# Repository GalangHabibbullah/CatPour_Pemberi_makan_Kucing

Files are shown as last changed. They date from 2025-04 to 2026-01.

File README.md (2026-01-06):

# 🐱 **CatPour** 🐱

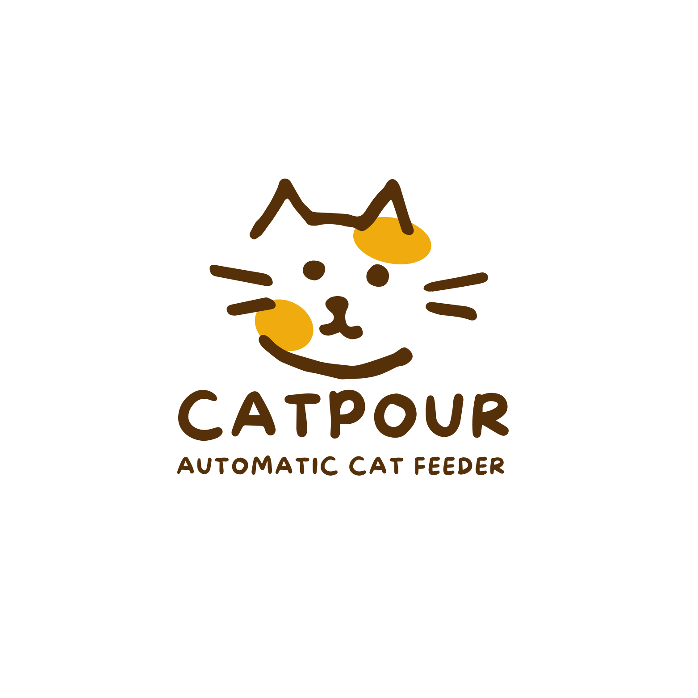
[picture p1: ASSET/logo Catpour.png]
Logo Catpour

---
🐱CatPour🐱 - SOLUSI CERDAS PARA CATLOVERS
Pernah merasa bersalah karena lupa memberi makan kucing karena sedang bepergian jauh? Atau bingung berapa porsi makan kucing yang dibutuhkan? CatPour hadir sebagai solusi cerdas para catlovers

Bayangkan kamu pulang ke rumah setelah berlibur. Kucingmu mengeong karena sedang kelaparan karena makanan yang telah kamu siapkan sudah habis tak bersisa. Tapi tenang kejadian itu tidak akan terulang ketika CatPour hadir.

CatPour hadir untuk menyelesaikan masalah para catlovers ketika sedeang bepergian. Sekarang Catlovers tidak perlu khawatir terhadap kucing piaraanya yang kelaparan, karena Catpour memberikan makanan secara otomatis sesuai jadwal dan dalam porsi yang cukup.

---
## 🎬 Commercial Video
Watch the demo (https://youtube.com/shorts/FYVQH_eTqcQ?si=p7NEjKbdANHq4uou)

---
## BUKU PANDUAN
📘 [Klik di sini untuk melihat buku proyek](./ASSET/buku.pdf)

## Link simulasi Wokwi
-- https://wokwi.com/projects/432622796153693185
-- [https://github.com/GalangHabibbullah/CatPour_Pemberi_makan_Kucing/tree/fe5401d0f07f7c271f16389e5ba98aa213cf10a5/PROGRAM/Wokwi](https://github.com/GalangHabibbullah/CatPour_Pemberi_makan_Kucing/issues/2#issue-3108791988)

---

## Link Video Demo
-- [https://github.com/GalangHabibbullah/CatPour_Pemberi_makan_Kucing/tree/d1d1669227759c1687d57a3f496b5af06effbe53/PROGRAM/Demo](https://github.com/GalangHabibbullah/CatPour_Pemberi_makan_Kucing/issues/1#issue-3108780877)

---

## TINGVERS
-- https://www.thingiverse.com/thing:7054144

---

## LINK PPT PRESENTASI


---

## LINK FIGMA
https://www.figma.com/design/loQbXYYag1uOcxZlFO6y6Z/Untitled?node-id=12-356&p=f&t=XrePOnV4dfjZV4aA-0

---
## 🎯 Objectives

- Mendeteksi jumlah sisa makanan pada bak penampungan makan  
- Memberi makan sesuai dengan porsi si kucing
- Memberi makan secara otomatis sesuai dengan jadwal makan.
- Menyediakan monitoring sisa makanan secara real-time melalui UART ke komputer
---
## 🧠 LATAR BELAKANG
Mempunyai kucing piaraan merupakan kesenangan sebagian orang, sering kali juga menjadi tantangan dalam hal pemberian makan, terutama bagi orang-orang sibuk atau yang sering  bepergian. Salah satu penyebab ketidakaturan ini bisa berdampak pada kesehatan kucing

**CatPour** memberikan solusi dengan cara pemberian makan otomatis sesuai porsi makan kucing  yang dibutuhkan.

---

Logo Catpour
## 🦾 Support BY :
>- Dosen Pengampu : Akhmad Hendriawan ST., MT. (NIP.197501272002121003)<br>
>- Mata kuliah : Workshop Mikrokontroller<br>
>- Program Studi : D3 Teknik Elektronika<br>
>- Politeknik Elektronika Negeri Surabaya<br>
---
## 😎 Team Member
| NRP | Nama | Jobdesk | Akun |
| :---: |:---: | :---: | :---:|
| 2123500004 | Rachmat Dhani G | 3D Design | [Dhani](https://github.com/rachmatdhani)
| 2123500005 | M. Ghibran K | Hardware | [Ghibran](https://github.com/Smolyyymokka)
| 2123500020 | Adhitya Ramadhani | UI / UX Design | [Firman](https://github.com/adhitya161004)
| 2123500025 | Adhi Pramana R | Programmer | [Rama](https://github.com/Adhi-Rama)
| 2123500030 | Galang Habibbullah| Project Manager | [Galang](https://github.com/GalangHabibbullah)
---
## 🔗 KOMPONEN 🔗 

Proyek ini mengembangkan sistem pemberian makan kucing otomatis berbasis IoT menggunakan komponen utama seperti **Arduino Uno**, **RTC (Real-Time Clock)**, **Loadcell**, dan **sensor HC-SR04**. 
| Komponen | Fungsi |
|---|---|
| **Arduino Uno** | Berfungsi sebagai mikrokontroler utama yang mengontrol sistem, komunikasi sensor, dan pengaturan pemberian makan otomatis. |
| **RTC** | Menjaga sinkronisasi waktu untuk pemberian makan sesuai jadwal yang telah diatur. |
| **Loadcell** | Mengukur berat makanan di wadah makan untuk memastikan porsi makanan yang tepat. |
| **Sensor HC-SR04** | Untuk memonitoring jumlah kesediaan ppakan dipenampungan pakan. |
---
## Desain 3D PCB
Desain 3D VIEW KICAD

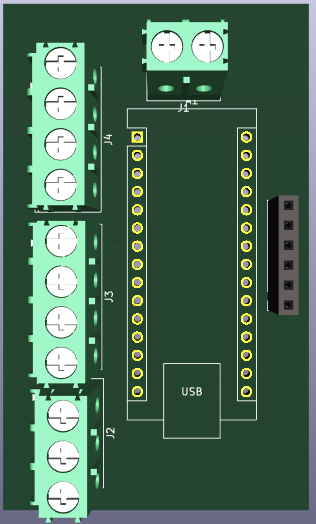
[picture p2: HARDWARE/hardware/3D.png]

---

## Desain Schematic PCB
Desain Schematic 

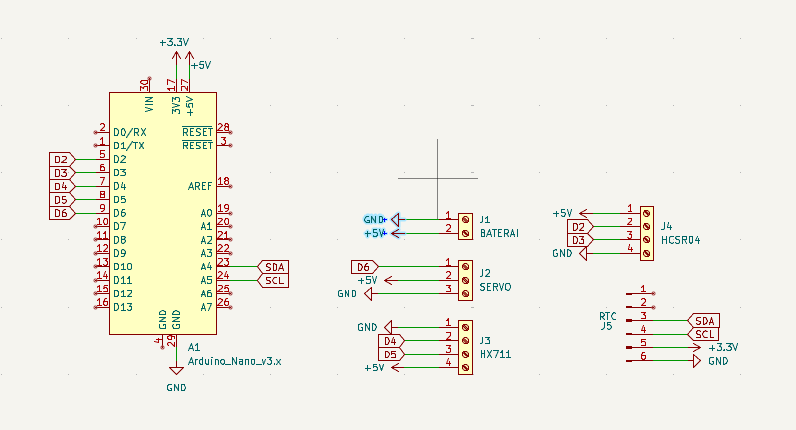
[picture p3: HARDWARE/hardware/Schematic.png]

---
## Desain Layout
Desain Layout PCB 

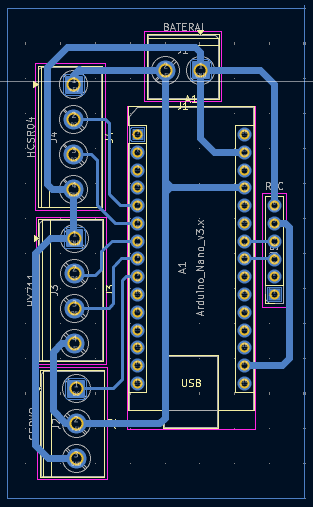
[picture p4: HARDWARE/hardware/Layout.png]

---
## Desain  PCB JADI
Hasil Cetak PCB

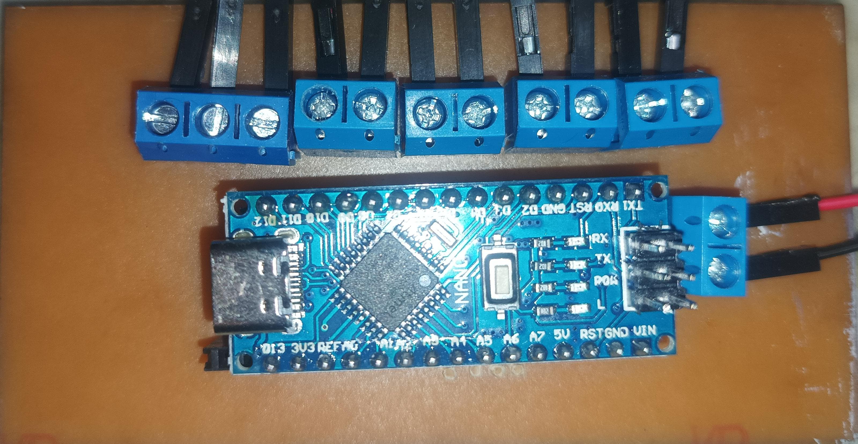
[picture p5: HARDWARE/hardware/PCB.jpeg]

---
## Desain 3D Alat
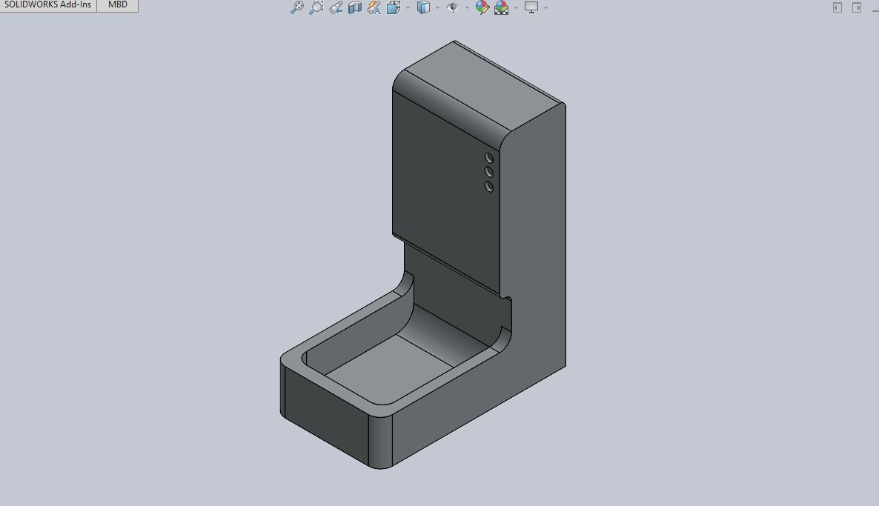
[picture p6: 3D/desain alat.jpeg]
Desain Alat

---
## Desain Jadi
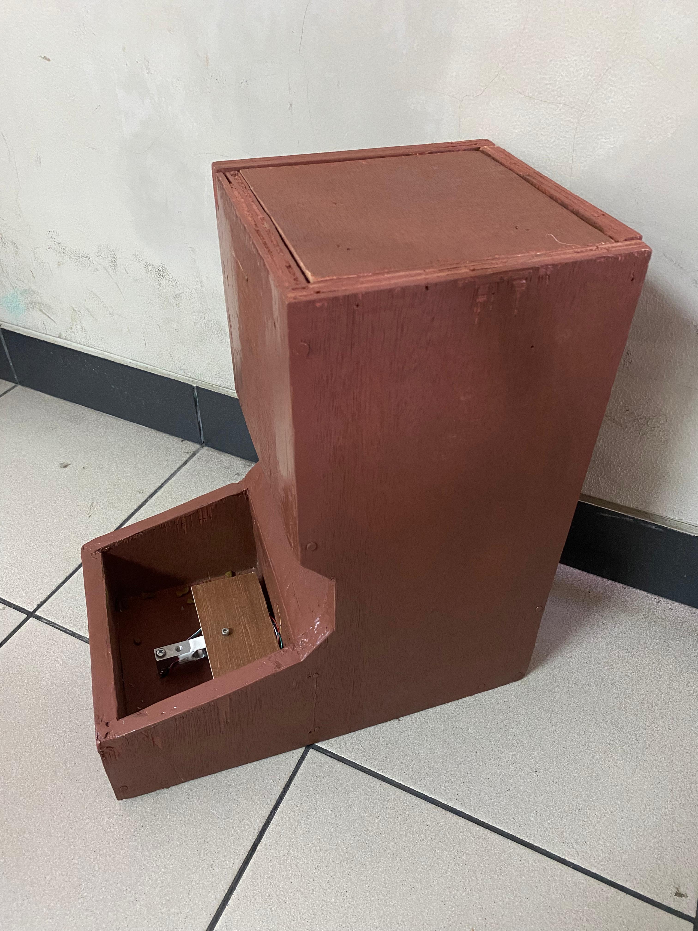
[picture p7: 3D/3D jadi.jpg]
Desain 3D Jadi

---
## 📊Diagram Blok
Diagram Blok Sistem.

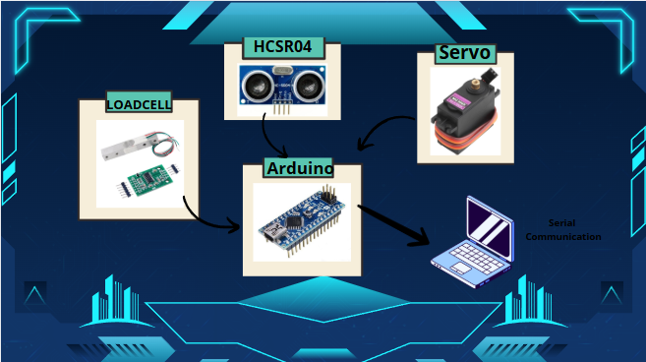
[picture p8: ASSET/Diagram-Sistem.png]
Diagram Komponen

---

## Software Tools

- [Arduino IDE](https://www.arduino.cc/en/software)
- [KiCad](https://kicad.org/)
- [Figma](https://www.figma.com/)
- [Visual Studio Code](https://code.visualstudio.com/)
---
## PRINSIP KERJA 
## Pembacaan penampungan makan
- Sensor HCSR 04 mengirim nilai jarak yang dikonversi menjadi nilai %
100 % = Penampungan Makan Full ; 0 % = Penampungan Makan Kosong
- Sensor Loadcell membaca berat pakan kucing yang keluar, apabila mencapai 20 gram maka servo akan menutup
## Pemrosesan oleh Arduino 
- Arduino  Membaca data  sensor secara berkala, Keputusan diambil untuk membuka servo atau menutup servo
## Tampilan Gui 
- GUI akan menampilkan data berat, sisa makan dan juga posisi servo

--- 
## Pengembangan Kedepannya
- Penambahan Kamera untuk pemantauan jarak jauh
- Penambahan Pemberi minum secara otomatis

---
## 📫 Contact Information

untuk segala informasi, kolaborasi, dan juga pemesanan alat bisa kirim email dibawah ini

**📧 Email:** galanghabibbullah3@gmail.com)

Hanya aktif saat jam kerja, berikan subjek pada email agar  dibalas lebih cepat

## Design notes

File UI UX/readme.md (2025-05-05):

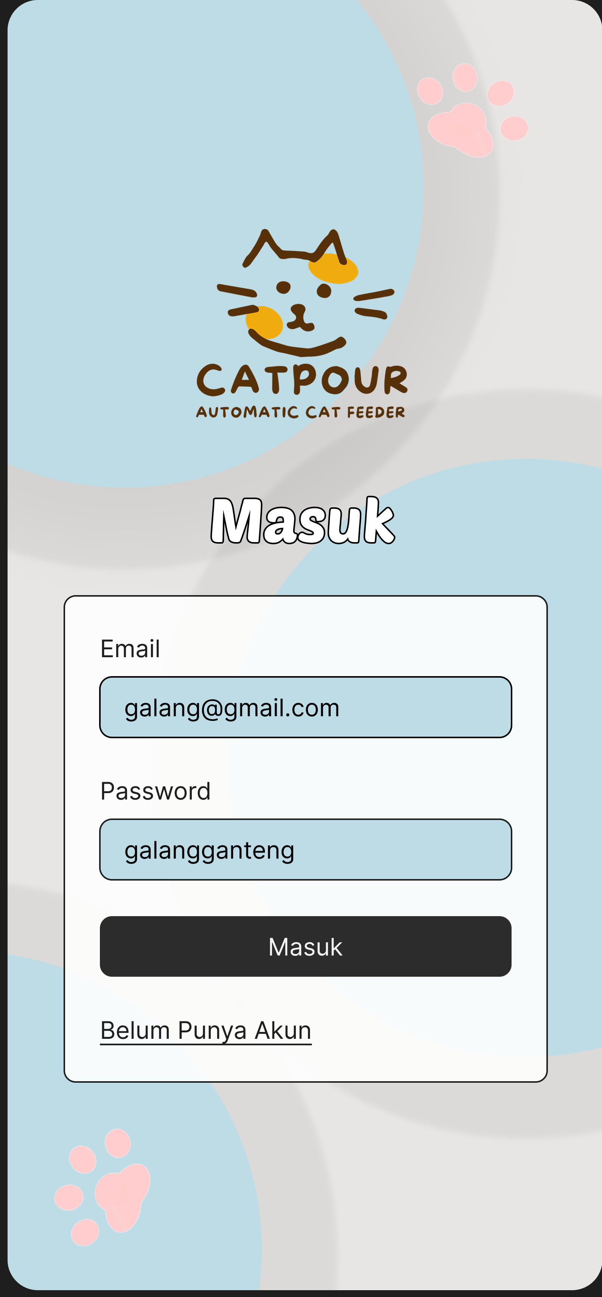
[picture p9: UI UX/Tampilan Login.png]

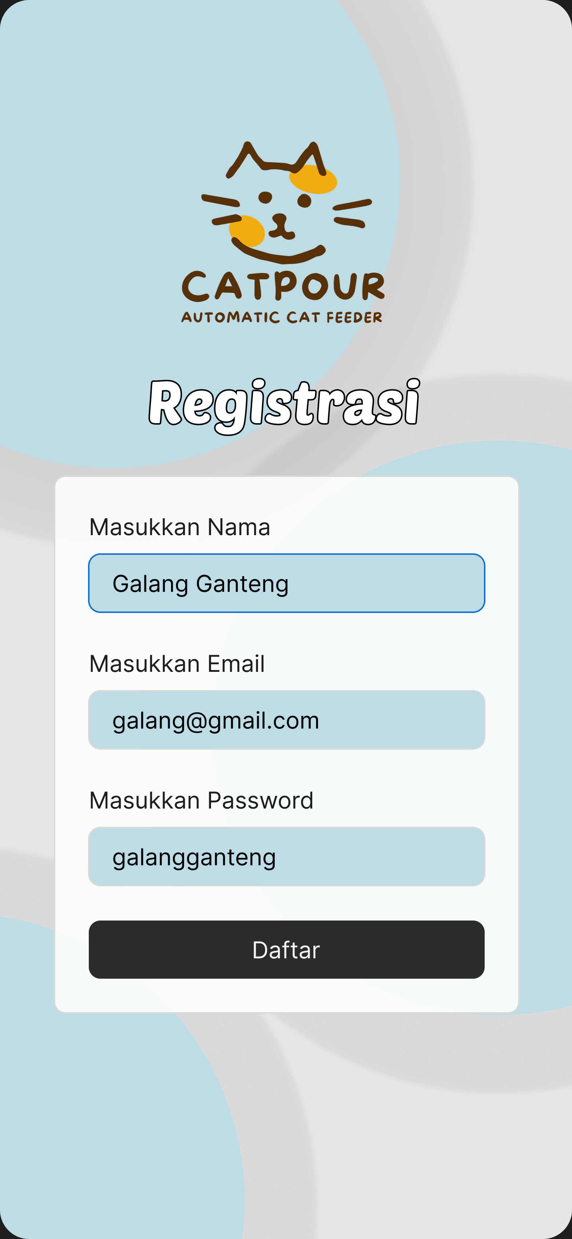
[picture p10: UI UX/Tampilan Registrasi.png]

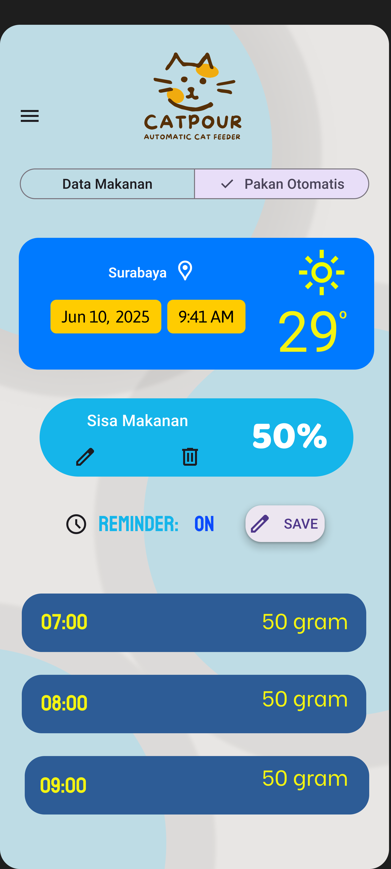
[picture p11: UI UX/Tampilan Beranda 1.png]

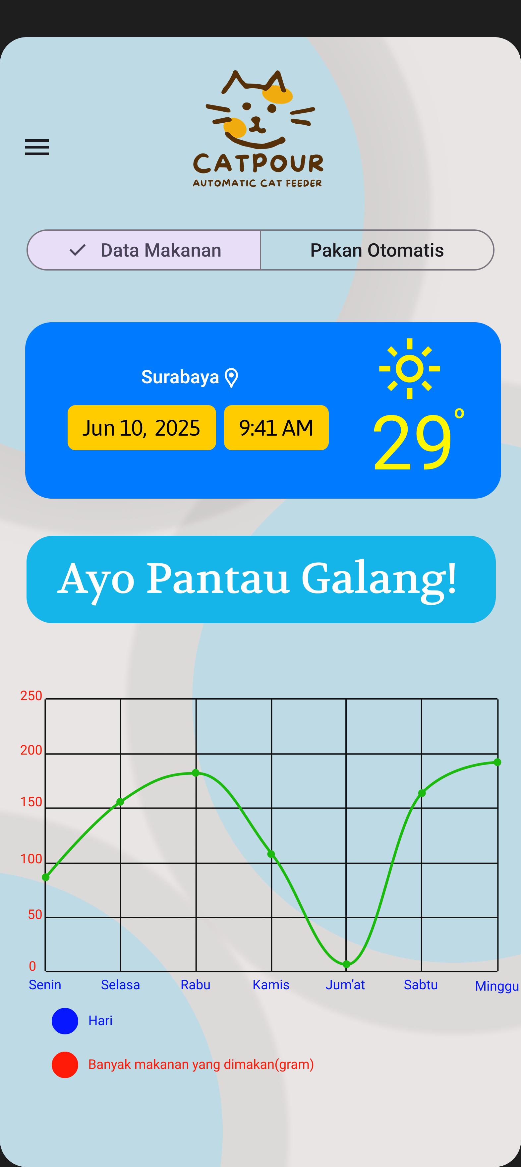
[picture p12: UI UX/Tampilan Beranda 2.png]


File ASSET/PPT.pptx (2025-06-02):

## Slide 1

catpour

(alat pemberi makan kucing otomatis)

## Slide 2

Anggota kelompok

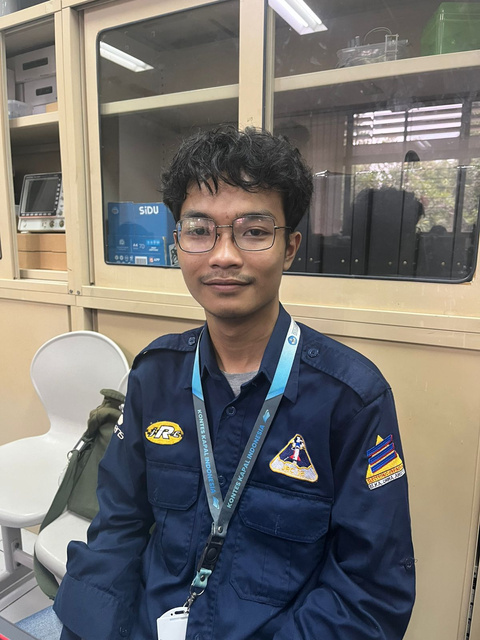
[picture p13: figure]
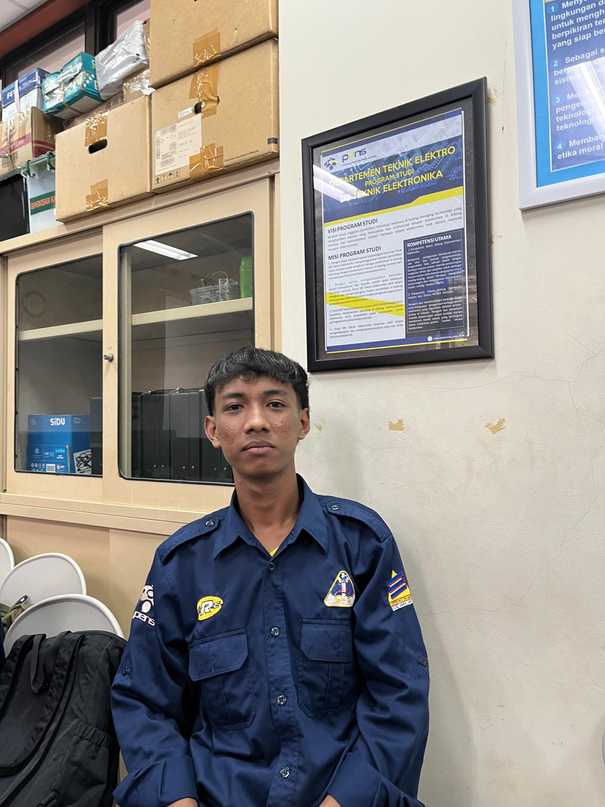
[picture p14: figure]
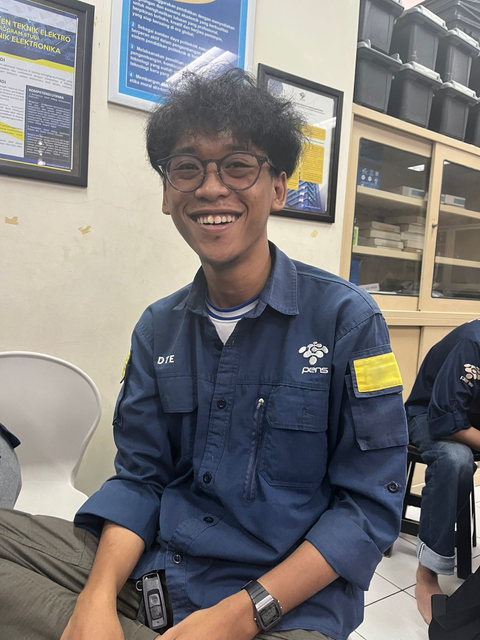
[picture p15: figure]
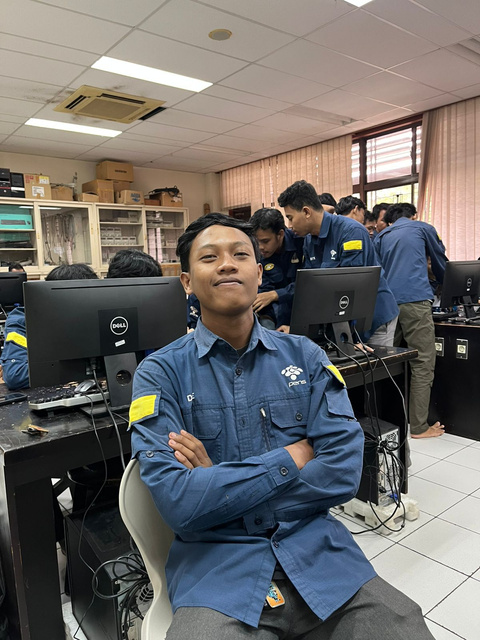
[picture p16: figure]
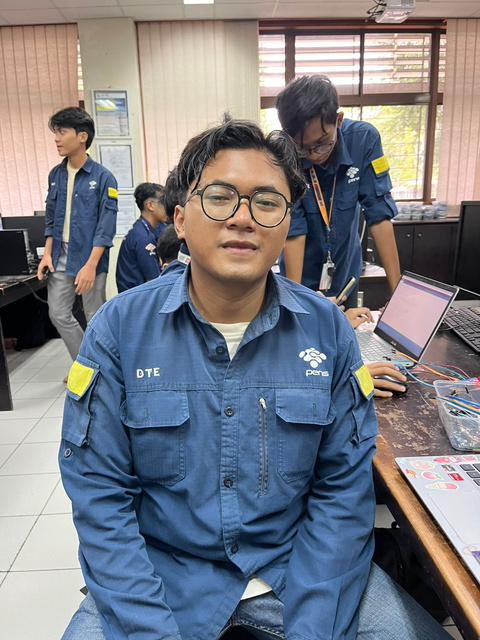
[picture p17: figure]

Rachmat Dhani G
2123500004
3D Design

Muhammad Ghibran
2123500005
Hardware

Adhitya R.N.F
2123500020
UI/UX Design

Adhi Pramana
2123500025
Programer

Galang Habibbullah
2123500030
Project Manager

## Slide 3

latar belakang
catpour

Banyak pemilik kucing mengalami kesulitan dalam memberi makanan kucing secara teratur karena kesibukan atau berpergian keluar rumah. Pemberian pakan yang tidak teratur ini bisa berdampak pada kesehatan kucing. Untuk mengatasi masalah tersebut, Maka kelompok kami merancang alat yang bernama CatPour yaitu alat pemberi makan kucing secara otomatis yang dapat menjadwalkan dan mengatur porsi makanan. Dengan bantuan CatPour pemilik dapat memberi makan kucing secara teratur meskipun pemilik kucing memiliki kesibukan dan berpergian diluar rumah. Dengan Catpour pemilik tidak perlu khawatir kucing peliharaanya merasa kelaparan.

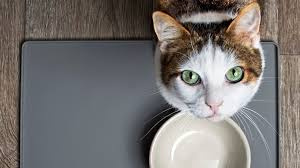
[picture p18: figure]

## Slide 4

rumusan masalah

Bagaimana merancang alat pemberi makan kucing otomatis yang dapat bekerja secara terjadwal?

2

Bagaimana cara mengatur porsi makanan kucing secara otomatis dan akurat?

3

Bagaimana memastikan alat bekerja secara stabil dan aman bagi hewan peliharaan?

1

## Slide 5

Tujuan

Tujuan dari pembuatan alat CatPour ini adalah mengatasi permasalahan yang terjadi pada pemelihara kucing yang memiliki kesibukan dan sering berpergian. Alat ini menja solusi cerdas, praktis, dan penuh kasih bagi para pemilik kucing yang ingin memastikan hewan peliharaannya tetap terjaga kesehatannya, meskipun mereka sedang sibuk atau bepergian. CatPour hadir tidak hanya sebagai alat pemberi makan otomatis, tetapi sebagai "asisten pribadi kucing" yang mampu menyesuaikan waktu, porsi, dan jenis makanan dengan cerdas.

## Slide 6

manfAat catpour

1

Pemberian makan secara terjadwal :
Alat ini membantu pemilik dapat mengatur jadwal pemberian makan tepat waktu meskipun sedang sibuk atau berpergian.

2

Meningkatkan efisiensi waktu :
Pemilik tidak perlu khawatir terhadap pemberian makanan pada kucingnya sehingga pemilik dapat melakukan kegiatan lainnya.

3

Mengatur porsi dengan akurat :
Alat ini Mencegah kucing peliharaan makan secara berlebihan atau kurang, yang bisa berdampak pada kesehatan kucing.

4

Membantu Membentuk Rutinitas Makan
Pemberian pakan yang terjadwal dapat membentuk rutinitas kucing sehingga pemilik dapat mengetahui jadwal makan kucingnya.

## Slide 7

HardWare

Berikut adalah diagram sistem dari CatPour :

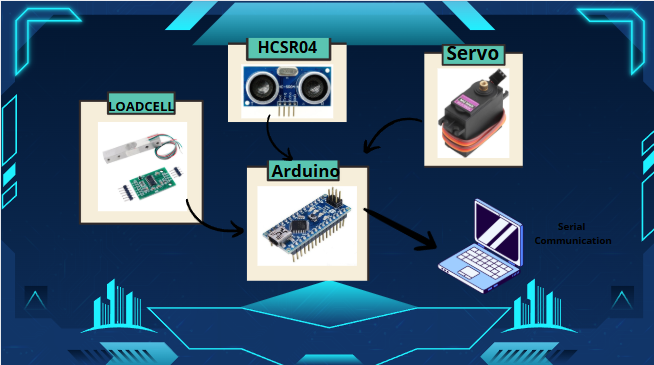
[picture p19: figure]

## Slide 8

Design Hardware

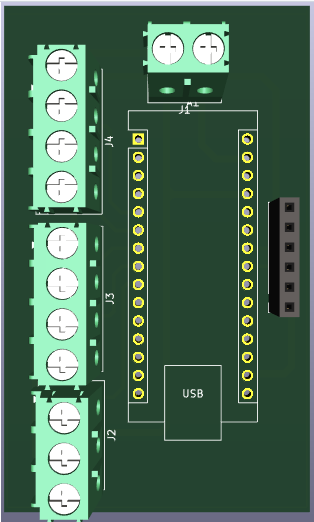
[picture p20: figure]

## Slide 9

Design ALat

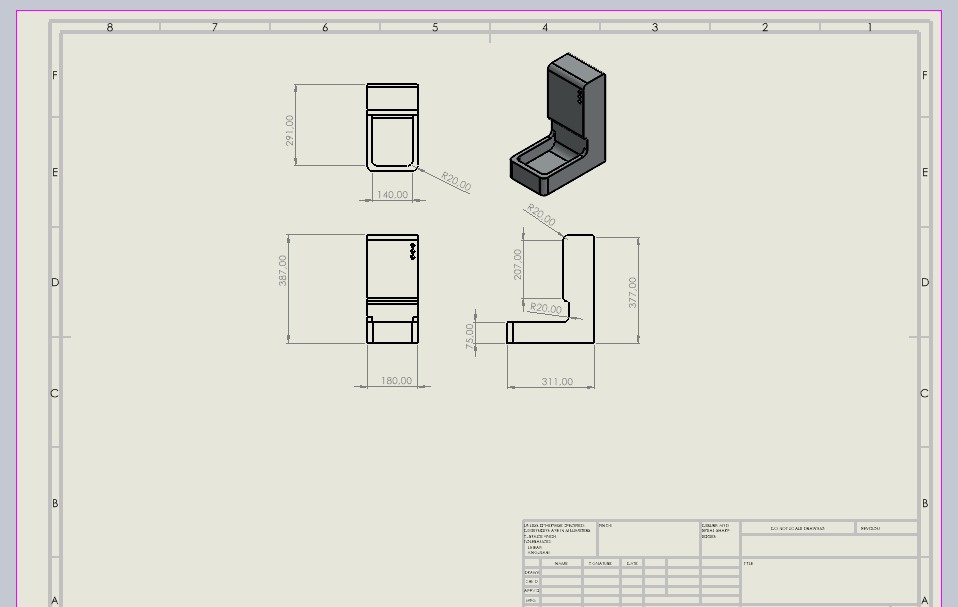
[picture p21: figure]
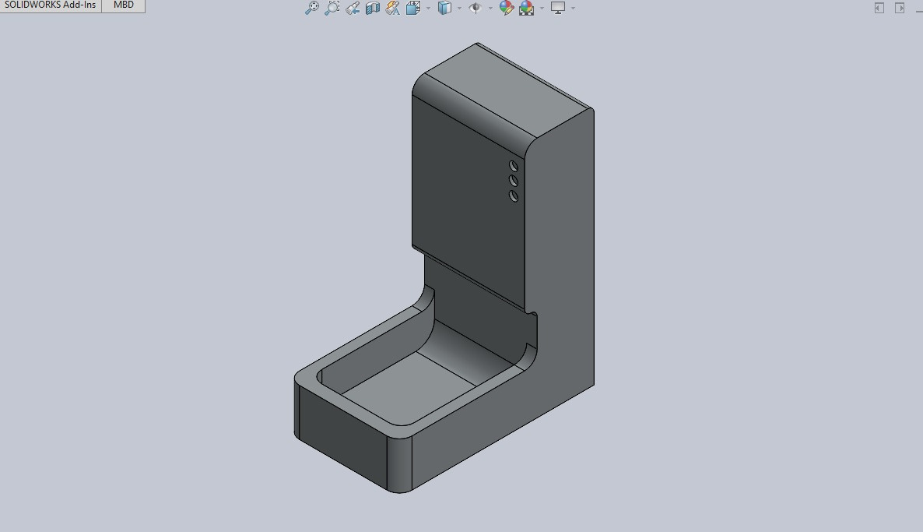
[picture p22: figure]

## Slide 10

UI/UX

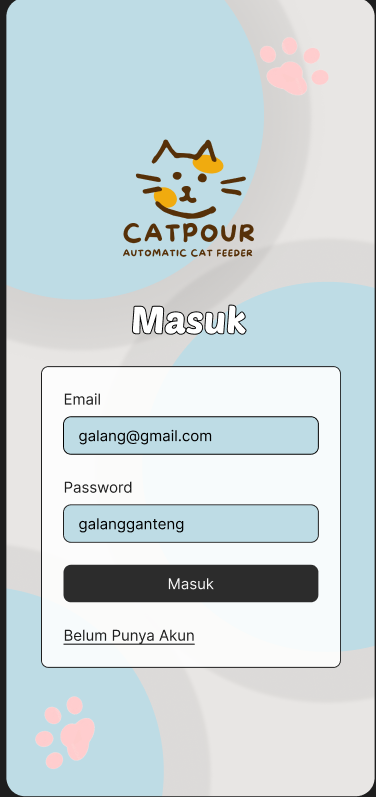
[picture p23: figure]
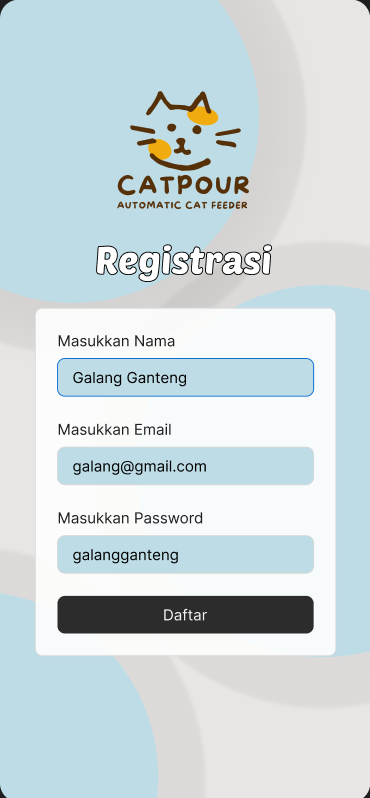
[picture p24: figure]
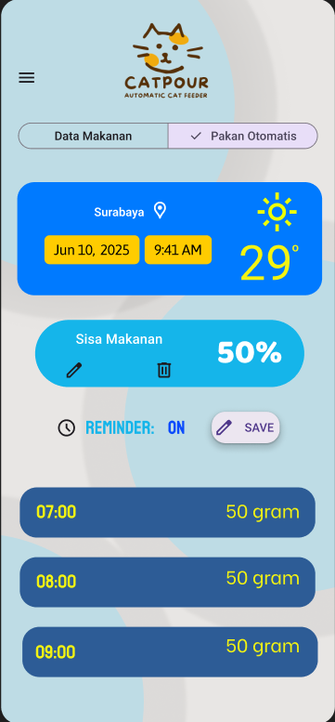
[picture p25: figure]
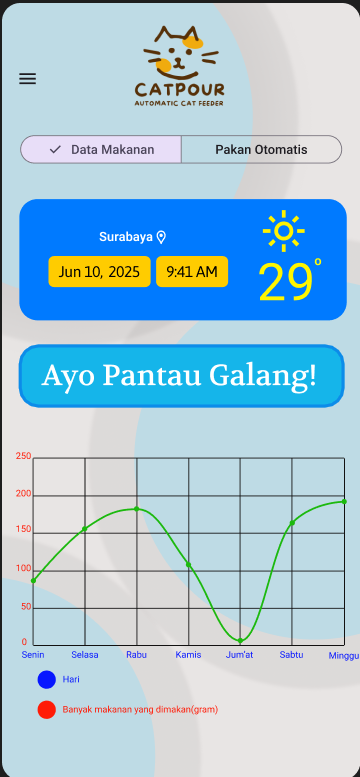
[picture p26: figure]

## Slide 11

Terima
kasih

Semoga Bermanfaat

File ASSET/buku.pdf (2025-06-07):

ww

## www

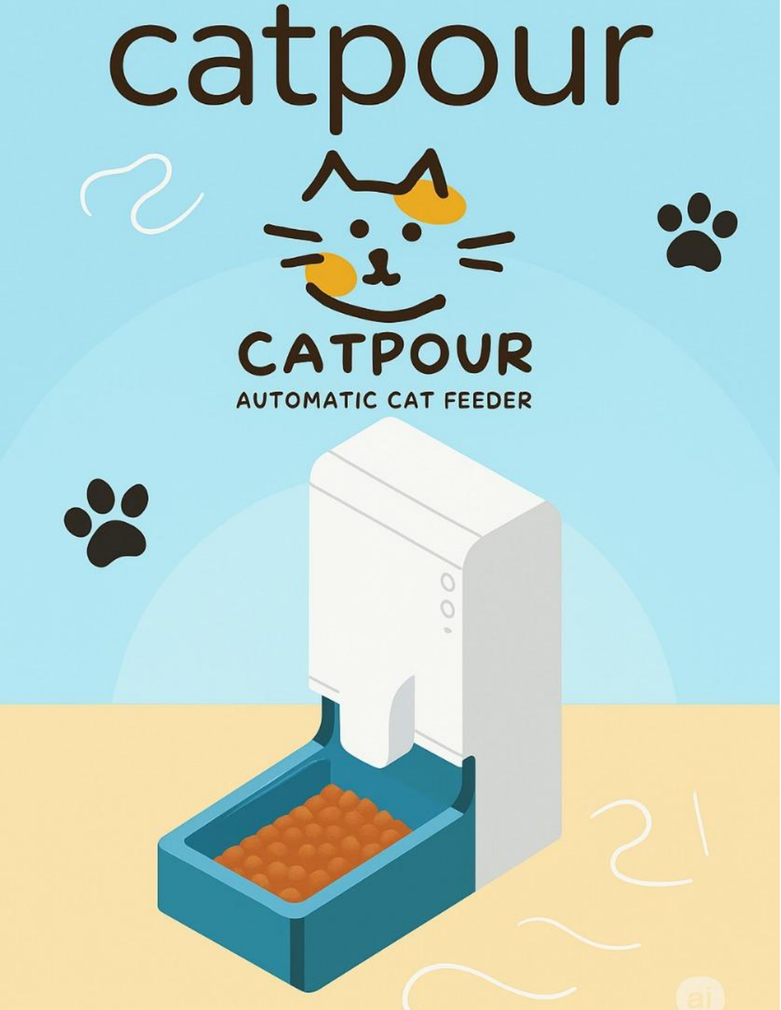
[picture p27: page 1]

## wwww

## wwww

## wwww

## wwwww

## wwwww

## wwwww

## wwww

## DAFTAR ISI

### 5.4 Waktu Respon Sistem | 80

BAB VI DAMPAK MANFAAT DAN PENGEMBANGAN | 82

### 6.1 Manfaat Bagi Pengguna dan Hewan Peliharaan | 82

### 6.2 Dampak Sosial dan Edukasi | 84

### 6.3 Potensi Pengembangan Teknologi | 86

### 6.4 Dampak Terhadap Inovasi Lokal dan Ekonomi Kreatif | 90

### 6.5 Arah Pengembangan Jangka Panjang | 93

BAB VII PENUTUP | 97

### 7.1 Kesimpulan | 97

### 7.2 Keterbatasan | 100

### 7.3 Saran | 102

## BAB I PENDAHULUAN

## 1.1 Latar Belakang

Di era globalisasi yang ditandai oleh percepatan teknologi informasi dan otomasi, kehidupan manusia telah mengalami transformasi signifikan di berbagai bidang, termasuk dalam aspek domestik seperti perawatan hewan peliharaan. Hewan peliharaan tidak lagi hanya dipandang sebagai penjaga atau penghibur semata, tetapi telah menjadi bagian integral dari keluarga dan kehidupan sosial masyarakat modern. Fenomena ini dapat dilihat dari meningkatnya minat terhadap adopsi hewan peliharaan, terutama kucing, yang telah menjadi salah satu hewan peliharaan paling populer di dunia.

Menurut data dari berbagai asosiasi pecinta hewan internasional dan lokal, populasi kucing peliharaan terus meningkat setiap tahunnya. Hal ini tidak terlepas dari karakteristik kucing yang cenderung mandiri, tidak membutuhkan ruang yang luas, dan mampu beradaptasi dengan gaya hidup urban yang padat. Dalam konteks ini, muncul berbagai tantangan baru dalam hal perawatan dan pemeliharaan kucing, khususnya terkait pemenuhan kebutuhan dasar seperti pemberian pakan.

Pemberian pakan merupakan aspek penting dalam menjaga kesehatan dan kesejahteraan kucing. Ketidakteraturan dalam jadwal dan jumlah pakan dapat menyebabkan obesitas, malnutrisi, hingga gangguan perilaku. Namun, kesibukan pemilik sering kali membuat pemberian pakan secara konsisten menjadi sulit. Situasi seperti dinas luar kota, liburan, atau kondisi darurat menyebabkan sistem pemberian pakan manual menjadi tidak memadai.

Solusi yang diperlukan adalah alat pemberi pakan otomatis yang bekerja secara mandiri, teratur, terukur, dan dapat dipantau dari jarak jauh. Dalam konteks ini, teknologi otomatisasi dan Internet of Things (IoT) menjadi jawaban. Otomatisasi kini menjadi bagian penting dari revolusi industri keempat. Perangkat pintar (smart devices) memungkinkan fungsi kompleks dijalankan secara otomatis. Dalam bidang perawatan hewan, berbagai produk seperti penyaring kotoran otomatis dan mainan interaktif telah dikembangkan, namun umumnya masih mahal dan kurang fleksibel.

Berawal dari kondisi ini, dikembangkanlah "Cat Pour", sebuah alat pemberi pakan kucing otomatis yang berbasis mikrokontroler Arduino Nano. Arduino Nano dipilih karena ukurannya kecil, hemat energi, dan kompatibel dengan berbagai sensor dan aktuator. Sistem ini memanfaatkan sensor ultrasonik HC-SR04 untuk mendeteksi posisi wadah, load cell HX711 untuk mengukur berat pakan, dan servo motor sebagai pengatur saluran pakan. Keseluruhan komponen ini bekerja terpadu, memastikan pemberian pakan terjadwal dan sesuai takaran. Desain mekanik alat ini menggunakan kayu triplek sebagai rangka utama, dipilih karena kuat, mudah dibentuk, ramah lingkungan, dan estetis. "Cat Pour" tidak hanya efisien secara fungsi, tetapi juga menyatu secara visual dengan interior rumah.

Sistem ini memiliki potensi dikembangkan menjadi perangkat IoT dengan penambahan modul ESP8266 atau ESP32, memungkinkan kendali dan pemantauan melalui internet. Pengguna dapat menerima notifikasi, mengubah jadwal, atau memantau status pakan dari jarak jauh Selain fungsi praktis, "Cat Pour" juga merupakan sarana edukatif. Dengan desain open-source, alat ini dapat menjadi media pembelajaran untuk mikrokontroler, sensor, aktuator, dan IoT bagi pelajar, mahasiswa, serta komunitas teknologi. Akses terbuka terhadap desain dan kode sumbernya memungkinkan inovasi lebih lanjut.

Dari sisi komersial, "Cat Pour" memiliki potensi sebagai produk lokal yang bersaing dengan produk luar. Biaya produksi yang lebih rendah dan kemudahan pengembangan menjadikan alat ini solusi alternatif yang terjangkau. Dengan prinsip mekatronika, otomasi, dan IoT, "Cat Pour" menjadi simbol integrasi teknologi dalam kehidupan rumah tangga. Alat ini merupakan solusi praktis, sarana edukasi, dan produk inovatif yang mendorong perkembangan teknologi terapan di Indonesia.

Tren Global dalam Perawatan Hewan Peliharaan

Perkembangan industri hewan peliharaan global terus menunjukkan pertumbuhan signifikan. Laporan Global Pet Care Market Outlook memperkirakan pasar ini mencapai lebih dari 250 miliar USD pada tahun 2030. Pertumbuhan ini didorong oleh meningkatnya populasi hewan peliharaan dan kesadaran pemilik akan pentingnya perawatan dan kenyamanan hewan.

Di negara maju seperti Amerika Serikat, Jepang, dan negara Eropa Barat, pengeluaran tahunan untuk kebutuhan hewan sangat besar, mencakup makanan, alat bantu, dan layanan kesehatan. Di Indonesia, tren serupa terlihat dari semakin banyaknya toko hewan, klinik, dan komunitas pecinta hewan yang aktif.

Kebutuhan akan perangkat praktis dan efisien seperti "Cat Pour" semakin relevan. Selain itu, adopsi perangkat IoT dalam rumah tangga juga mendukung kehadiran alat ini. Perangkat seperti kamera pengawas hewan dan alat pakan otomatis kini menjadi bagian gaya hidup modern "Cat Pour" berada di posisi strategis untuk menjawab kebutuhan ini. Dengan perpaduan fungsi praktis dan teknologi digital, alat ini menjadi solusi cerdas dalam ekosistem rumah pintar yang berkembang pesat.

Studi Kasus Alat Serupa di Pasar Global dan Dampaknya terhadap Inovasi Lokal

Di berbagai negara, alat pemberi pakan hewan otomatis telah berkembang menjadi produk komersial yang canggih. Beberapa merek seperti PetSafe, WOPET, dan Petlibro memimpin pasar global dengan menawarkan fitur seperti pengaturan waktu pakan melalui aplikasi smartphone, kamera pemantau, serta koneksi Wi-Fi yang memungkinkan interaksi jarak jauh dengan hewan peliharaan. Produk-produk ini menunjukkan bagaimana integrasi teknologi digital dalam kehidupan rumah tangga telah menjadi kebutuhan yang semakin lazim.

PetSafe misalnya, menawarkan perangkat yang dapat menyesuaikan jumlah pakan berdasarkan kebutuhan kalori harian kucing, dengan sistem pemantauan berat badan. Sementara WOPET menghadirkan fitur voice recording yang memungkinkan pemilik menyapa kucingnya setiap kali pakan dikeluarkan. Petlibro menambahkan fungsi backup battery untuk mengatasi pemadaman listrik agar sistem tetap berfungsi.

Keberadaan alat-alat ini tidak hanya mencerminkan kemajuan teknologi, tetapi juga mendorong inovator lokal untuk menciptakan produk serupa yang lebih terjangkau dan sesuai dengan konteks sosial ekonomi masyarakat Indonesia. Sayangnya, harga alat impor relatif mahal dan tidak selalu cocok dengan kebutuhan lokal, baik dari segi daya listrik, konektivitas internet, maupun desain fisik. Hal ini membuka peluang besar bagi inovasi lokal seperti "Cat Pour" untuk mengisi celah pasar. Dengan mengadaptasi teknologi terbuka dan menggunakan komponen yang tersedia di dalam negeri, "Cat Pour" dapat dikembangkan sebagai alternatif yang ekonomis namun tetap fungsional. Inovasi lokal ini juga memungkinkan penyesuaian lebih fleksibel terhadap kebutuhan pengguna di Indonesia, seperti fitur manual override tanpa koneksi internet, atau desain yang disesuaikan dengan kondisi rumah tropis.

Lebih dari itu, adanya inspirasi dari produk global memacu proses lokalisasi inovasi teknologi. Inovator lokal dapat mempelajari fitur-fitur unggulan dari produk luar, lalu menyederhanakannya agar sesuai dengan kemampuan teknis dan daya beli masyarakat. Ini tidak hanya mendorong kreativitas, tetapi juga menciptakan ekosistem teknologi yang berkelanjutan, mandiri, dan berorientasi pada pemecahan masalah nyata. Dengan demikian, studi kasus terhadap alat serupa di pasar global menjadi rujukan penting dalam pengembangan "Cat Pour". Tidak hanya untuk membandingkan fitur dan harga, tetapi juga sebagai pijakan dalam menciptakan produk yang relevan, berdampak sosial, dan kompetitif di pasar lokal maupun internasional.

Analisis Kelayakan Teknis dan Ekonomi

Dalam perancangan dan pengembangan sebuah produk teknologi, aspek kelayakan teknis dan ekonomi menjadi dua pilar utama yang saling melengkapi. Kelayakan teknis berkaitan dengan kemampuan alat untuk berfungsi sesuai dengan tujuan yang diinginkan, sedangkan kelayakan ekonomi berkaitan dengan efisiensi biaya dan keberlanjutan produksi serta pemasaran alat dalam jangka panjang.

Secara teknis, "Cat Pour" dirancang menggunakan komponen-komponen yang sudah teruji dan tersedia secara luas di pasaran lokal. Arduino Nano sebagai otak dari sistem menawarkan kemudahan dalam pemrograman serta kompatibilitas tinggi dengan sensor dan aktuator seperti

HC-SR04, HX711, dan servo motor. Pemilihan komponen ini mempertimbangkan faktor kemudahan perawatan, harga terjangkau, serta dokumentasi teknis yang melimpah di berbagai platform online.

Selain itu, desain alat juga memungkinkan modularitas, di mana setiap komponen dapat diganti atau ditingkatkan tanpa harus membongkar keseluruhan sistem. Misalnya, jika pengguna ingin meng-upgrade sistem ke versi IoT, cukup menambahkan modul Wi-Fi seperti ESP8266 atau ESP32 tanpa perlu mengubah keseluruhan arsitektur alat. Ini menambah fleksibilitas serta memperpanjang umur pakai alat.

Dari sisi ekonomi, estimasi biaya pembuatan "Cat Pour" sangat kompetitif. Dengan kisaran biaya produksi di bawah Rp500.000 untuk versi dasar, alat ini memiliki nilai jual yang jauh lebih rendah dibandingkan produk impor serupa yang bisa mencapai jutaan rupiah. Selain itu, penggunaan bahan lokal seperti kayu triplek menurunkan biaya produksi sekaligus meningkatkan nilai estetika dan keberlanjutan.

Potensi komersialisasi alat ini juga tinggi, terutama jika dikembangkan melalui pendekatan komunitas maker dan startup teknologi. Dengan model bisnis berbasis open-source dan produksi skala kecil hingga menengah, "Cat Pour" bisa dipasarkan melalui e-commerce lokal, bazar teknologi, atau kerja sama dengan toko hewan peliharaan. Dari kedua aspek ini, dapat disimpulkan bahwa "Cat Pour" layak dikembangkan secara teknis dan ekonomis. Keberhasilannya akan sangat bergantung pada strategi pengembangan lebih lanjut, termasuk uji lapangan, penyempurnaan desain, serta pendekatan pemasaran yang tepat sasaran.

## 1.2. Rumusan Masalah

Untuk mewujudkan alat pemberi pakan kucing otomatis bernama “Cat Pour”, diperlukan berbagai kajian teknis, mekanis, dan fungsional. Alat ini dirancang tidak hanya untuk memudahkan pemilik hewan peliharaan dalam memberikan makan secara terjadwal, tetapi juga untuk memastikan bahwa pakan yang diberikan sesuai dengan kebutuhan nutrisi harian kucing. Oleh karena itu, beberapa rumusan masalah yang perlu dikaji dan dijawab dalam perancangan dan implementasi alat ini adalah sebagai berikut:

### 1. Bagaimana merancang alat pemberi pakan otomatis yang efektif dan efisien bagi hewan

peliharaan, khususnya kucing, menggunakan Arduino Nano sebagai pusat kontrol?

Perlu dikaji bagaimana Arduino Nano dapat mengendalikan seluruh komponen sistem dengan keterbatasan pin I/O, kapasitas memori, dan kecepatan pemrosesan. Efektivitas perancangan juga harus mempertimbangkan aspek modularitas, kemudahan perawatan, efisiensi konsumsi daya, serta skalabilitas sistem jika ingin ditambahkan fitur lain di masa mendatang seperti konektivitas IoT atau aplikasi pemantauan berbasis Android/iOS.

### 2. Bagaimana integrasi sensor ultrasonik HC-SR04 dapat digunakan untuk mendeteksi

kehadiran kucing atau keberadaan wadah pakan secara akurat dan responsif?

Sensor HC-SR04 bekerja berdasarkan pantulan gelombang ultrasonik untuk mengukur jarak. Permasalahannya adalah bagaimana mengatur posisi dan orientasi sensor agar tidak tertipu oleh gerakan sekitar, perubahan posisi wadah, atau gangguan benda lain. Selain itu, perlu dirancang metode filterisasi data atau rata-rata pembacaan untuk meningkatkan akurasi dan menghindari false trigger.

### 3. Bagaimana memanfaatkan load cell HX711 untuk mengukur berat pakan yang keluar agar

dapat dikontrol sesuai kebutuhan harian kucing?

Pemanfaatan load cell harus mempertimbangkan akurasi pengukuran berat dalam kisaran gram, kestabilan pembacaan dalam jangka waktu tertentu, dan pengaruh gangguan mekanik seperti getaran atau gaya tekan dari luar. Selain itu, diperlukan perancangan algoritma pengendalian agar berat pakan yang diberikan sesuai dengan batas yang telah diprogram, serta dapat dikalibrasi ulang sesuai kebutuhan.

4. Bagaimana mekanisme kerja servo motor dapat digunakan untuk membuka dan menutup saluran pakan dengan akurasi tinggi dan respons cepat?

Servo motor digunakan sebagai aktuator untuk membuka dan menutup pintu saluran pakan. Tantangan yang muncul meliputi penentuan sudut bukaan ideal, kecepatan respon, serta ketahanan servo terhadap beban dan siklus kerja berulang. Sistem mekanik harus mampu mentransfer gerakan rotasi servo menjadi gerakan pembuka/penutup yang presisi dan tidak macet akibat penumpukan pakan.

### 5. Bagaimana menyusun sistem elektronik dan mekanik dalam wadah berbahan kayu triplek

yang stabil dan tahan lama sesuai gambar kerja yang ada?

Struktur alat harus dirancang ergonomis, ringkas, dan tahan lama. Material triplek dipilih karena ringan, mudah dibentuk, dan cukup kuat untuk aplikasi non-industri. Namun, perlu diperhitungkan bagaimana peletakan komponen elektronik agar terlindungi dari debu, kelembapan, dan gangguan luar. Sistem kabel, sensor, dan motor harus tertata rapi serta mudah dalam proses perawatan dan perbaikan.

### 6. Bagaimana mengatur logika dan pemrograman Arduino Nano agar sistem bekerja secara

otomatis berdasarkan waktu dan parameter berat tertentu?

Permasalahan yang harus dikaji mencakup pembuatan flowchart logika kerja, penggunaan timer atau RTC (Real Time Clock) eksternal jika diperlukan, serta bagaimana mengatur waktu dan batas berat yang fleksibel melalui kode pemrograman. Selain itu, sistem harus mampu mengenali status sensor secara real-time dan merespons sesuai kondisi, seperti membuka pakan hanya jika kucing terdeteksi dan berat pakan kurang dari batas minimum.

### 7. Apa tantangan teknis yang mungkin timbul dalam integrasi antara komponen elektronik

dan struktur mekanik, serta bagaimana cara mengatasinya?

Tantangan integrasi mencakup kompatibilitas dimensi antar komponen, pemanasan komponen elektronik, kestabilan sumber daya listrik, serta gangguan elektromagnetik atau noise. Selain itu, perlu dipikirkan bagaimana membuat sistem yang tetap bekerja meski sebagian komponen mengalami gangguan (fail-safe mechanism), serta cara mudah melepas atau mengganti komponen yang rusak.

### 8. Bagaimana merancang sistem pemberian pakan secara otomatis berdasarkan jadwal

waktu tertentu dan menyesuaikannya dengan kebiasaan makan kucing?

Setiap kucing memiliki pola makan yang berbeda. Oleh karena itu, sistem perlu mampu menyimpan jadwal makan harian dan mengatur waktu pemberian pakan secara fleksibel. Rumusan masalah ini mencakup pembuatan sistem input data jadwal (baik melalui tombol manual, serial, atau integrasi aplikasi), serta penyimpanan memori internal (EEPROM) untuk menjamin data tetap tersimpan meskipun daya mati.

### 9. Bagaimana sumber daya listrik untuk sistem dapat dirancang agar hemat energi dan aman

digunakan di lingkungan rumah tangga?

Pemilihan sumber daya harus mempertimbangkan tegangan dan arus yang dibutuhkan oleh semua komponen, serta skenario power loss. Apakah sistem akan menggunakan adaptor listrik rumah tangga, atau disertai baterai cadangan sebagai backup? Rumusan ini juga mencakup bagaimana merancang sistem konversi tegangan yang stabil dan efisien, serta meminimalkan konsumsi daya dalam kondisi idle.

10. Bagaimana sistem dapat dikembangkan lebih lanjut menjadi berbasis IoT, sehingga pemilik dapat memantau dan mengatur pemberian pakan melalui ponsel?

Pengembangan sistem ke arah Internet of Things akan membuka potensi besar dalam pemantauan dan pengendalian jarak jauh. Namun, perlu dijawab bagaimana menambahkan modul komunikasi seperti ESP8266 atau ESP32 secara teknis, mengatur komunikasi data, serta merancang antarmuka pengguna (UI/UX) yang ramah untuk digunakan. Hal ini juga mencakup tantangan keamanan data dan respons sistem terhadap perintah jarak jauh.

### 11. Bagaimana membuat sistem antarmuka pengguna (UI) sederhana yang dapat

memberikan informasi status alat, seperti pakan tersisa, jadwal berikutnya, atau log aktivitas?

Perangkat seperti LCD 16x2, OLED, atau LED indikator dapat digunakan untuk memberikan umpan balik kepada pengguna. Rumusan masalah ini membahas bagaimana menyusun informasi tersebut agar mudah dipahami, tidak membingungkan, serta memberikan informasi real-time. UI ini juga dapat berguna sebagai alat debugging selama pengujian sistem.

### 12. Bagaimana merancang algoritma pemantauan dan pengendalian secara real-time agar

sistem dapat menyesuaikan respons berdasarkan data sensor terkini?

Dalam sistem ini, data dari sensor HC-SR04 dan HX711 akan terus berubah. Oleh karena itu, perlu dirancang algoritma yang dapat memproses data secara kontinu dan mengambil keputusan secara tepat waktu, misalnya menghentikan servo saat berat tercapai, atau mengabaikan pembacaan jika kucing belum muncul dalam jangka waktu tertentu.

### 13. Bagaimana menjaga keamanan makanan dari kontaminasi atau kerusakan akibat

lingkungan sekitar (debu, serangga, kelembapan)?

Desain wadah penyimpanan dan saluran pakan harus mampu menjaga kualitas pakan. Ini termasuk sistem penutup otomatis, penggunaan material food grade, serta desain mekanik agar tidak mudah terbuka oleh hewan lain atau anak-anak.

### 14. Bagaimana melakukan pengujian dan kalibrasi sistem secara menyeluruh untuk

memastikan akurasi dan keandalannya?

Rumusan ini mencakup metode pengujian sensor jarak dan berat, pengukuran waktu respon servo, pengujian sistem kerja secara berulang, serta teknik kalibrasi ulang sistem jika terjadi deviasi pengukuran. Hal ini penting untuk memastikan sistem bekerja dengan andal selama periode penggunaan yang panjang.

### 15. Bagaimana membuat sistem modular dan mudah diperbaiki, sehingga pengguna non-

teknis pun dapat melakukan pemeliharaan ringan?

Rancangan alat harus modular, di mana setiap bagian dapat dilepas pasang dengan mudah. Kabel harus diberi label atau konektor, dan pemrograman Arduino diatur agar dapat dimodifikasi ulang dengan mudah jika ingin mengubah parameter tertentu.

## 1.3 Tujuan

Pembuatan alat “Cat Pour” bertujuan untuk menciptakan sebuah sistem pemberi pakan otomatis untuk kucing yang cerdas, efisien, presisi, dan mudah diakses oleh masyarakat luas, khususnya pemilik hewan peliharaan yang memiliki keterbatasan waktu dan aktivitas padat. Berikut merupakan rincian dan pengembangan dari tujuan tersebut secara lebih komprehensif:

### 1. Merancang dan Membuat Prototipe Alat Pemberi Pakan Kucing Otomatis Berbasis

Arduino Nano. Tujuan utama dari pembuatan alat ini adalah merancang dan mengembangkan prototipe alat yang berbasis mikrokontroler Arduino Nano. Arduino Nano dipilih karena bentuknya yang kecil, konsumsi daya rendah, biaya yang terjangkau, serta kemampuannya dalam mengontrol berbagai perangkat input-output secara efisien. Dengan perangkat lunak pemrograman berbasis C/C++, pengguna dapat menyesuaikan logika operasional alat sesuai dengan kebutuhannya masing-masing.

Prototipe ini dirancang untuk dapat:

a. Beroperasi secara mandiri setelah pemrograman awal, tanpa perlu intervensi manusia dalam penggunaan sehari-hari.
b. Menjadi solusi teknologi terapan di bidang pet care dan smart home, dengan potensi pengembangan lanjutan seperti koneksi IoT, sistem kontrol berbasis aplikasi, dan monitoring berbasis cloud.
c. Mengedukasi pengguna tentang manfaat teknologi mikrokontroler dalam kehidupan sehari-hari.
2. Mengimplementasikan Sensor Ultrasonik HC-SR04 untuk Deteksi Keberadaan Kucing atau Posisi Mangkuk. Sensor ultrasonik HC-SR04 digunakan sebagai perangkat input utama dalam mendeteksi keberadaan kucing di dekat alat atau memastikan bahwa mangkuk makanan berada pada posisi yang benar sebelum pakan dikeluarkan. Deteksi ini sangat penting untuk mencegah kesalahan distribusi pakan, seperti tumpahnya pakan di luar mangkuk atau pemberian pakan saat mangkuk belum siap.

Tujuan dari penggunaan sensor ini meliputi:

a. Meningkatkan efisiensi dan akurasi sistem distribusi pakan.
b. Mencegah pemborosan dan kekacauan akibat pakan yang jatuh sembarangan.
c. Menambah unsur “real-time monitoring” dalam sistem agar alat mampu merespons kondisi aktual di lapangan.
3. Mengintegrasikan Load Cell HX711 sebagai Alat Ukur Berat Pakan yang Presisi. Untuk memastikan pakan yang diberikan kepada kucing dalam jumlah yang tepat, digunakan sensor load cell HX711. Load cell ini mampu mendeteksi berat dengan presisi tinggi, bahkan dalam satuan gram. Integrasi sensor ini bertujuan untuk:
a. Mencegah pemberian pakan yang berlebihan (overfeeding) maupun kekurangan (underfeeding), yang dapat berdampak pada kesehatan kucing.
b. Memberikan kemampuan kontrol pakan berbasis berat secara otomatis dan presisi.
c. Menyediakan data akurat terkait jumlah pakan yang telah diberikan, yang nantinya dapat dimanfaatkan dalam sistem log pencatatan atau pengelolaan nutrisi.

4. Menggunakan Servo Motor sebagai Aktuator untuk Mekanisme Pembukaan Jalur Pakan. Servo motor digunakan sebagai komponen aktuator utama dalam membuka dan menutup jalur keluarnya pakan. Mekanisme ini dirancang agar dapat bekerja berdasarkan sinyal dari mikrokontroler, menyesuaikan kondisi yang dibaca oleh sensor.

Tujuannya adalah untuk:

a. Mengatur aliran pakan secara terkontrol agar tidak berlebih atau menyumbat saluran.
b. Meningkatkan keandalan sistem distribusi pakan secara otomatis.
c. Meningkatkan keamanan alat, terutama dalam mencegah anak-anak atau hewan
lain | yang | mencoba | mengakses | pakan.
5. Merancang Struktur Alat dari Bahan Kayu Triplek yang Ergonomis, Ekonomis, dan Estetis. Pemilihan material triplek sebagai bahan dasar struktur alat didasarkan pada pertimbangan ekonomis, ketersediaan material yang mudah ditemukan, serta kemudahan dalam proses pemotongan, perakitan, dan finishing. Desain alat dibuat dengan mempertimbangkan aspek ergonomi (kemudahan penggunaan), estetika (penampilan menarik), serta kekuatan struktur.

Tujuan perancangan struktural ini adalah:

a. Menciptakan produk yang menarik secara visual dan dapat menyatu dengan desain interior rumah.
b. Menyediakan alat yang kokoh dan tahan lama untuk penggunaan jangka panjang.c
c. Memastikan bahwa alat dapat dirakit dan diperbaiki dengan mudah oleh pengguna tanpa perlu alat khusus.
6. Menguji Kinerja Alat dalam Berbagai Skenario Operasi. Untuk memastikan alat berfungsi optimal dalam kondisi nyata, dilakukan pengujian dalam berbagai skenario penggunaan, seperti:
- Pemberian pakan secara terjadwal: Menguji respons sistem terhadap waktu yang telah ditentukan dalam pemrograman.
- Pengukuran berat pakan: Menguji akurasi load cell dalam menakar jumlah pakan sesuai yang ditentukan.
- Deteksi objek: Menguji kepekaan dan akurasi sensor ultrasonik dalam mendeteksi keberadaan mangkuk atau kucing.

- Kegagalan sistem: Mensimulasikan kondisi error seperti habisnya pakan, mangkuk tidak tersedia, atau kerusakan servo untuk menguji kemampuan alat dalam memberikan peringatan atau tidak melanjutkan proses pemberian pakan.

Tujuan dari pengujian ini adalah:

a. Memastikan keandalan alat di berbagai kondisi penggunaan.
b. Mengidentifikasi potensi kelemahan sistem untuk perbaikan ke depan.
c. Menyediakan dokumentasi pengujian sebagai dasar pengembangan versi komersial.
7. Memberikan Solusi Praktis dan Terjangkau untuk Pemilik Kucing. Salah satu tujuan utama dari proyek ini adalah memberikan solusi nyata yang dapat membantu pemilik kucing dalam:
a. Menjaga pola makan hewan peliharaan mereka tetap konsisten meskipun mereka memiliki kesibukan atau sering bepergian.
b. Menghemat waktu dan tenaga yang biasanya diperlukan untuk memberi makan secara manual.
c. Memberikan ketenangan pikiran karena alat ini mampu bekerja secara mandiri dan terjadwal.

Selain itu, alat ini juga ditujukan untuk:

a. Menurunkan biaya pemeliharaan alat pemberi pakan otomatis dibandingkan dengan produk komersial yang ada di pasaran.
b. Memberikan alternatif DIY (Do It Yourself) yang dapat dibangun oleh siapa pun dengan sedikit pengetahuan teknis dan keterampilan dasar.
8. Memberikan Edukasi Teknologi dan Inovasi Berbasis Proyek. Proyek ini juga bertujuan untuk menjadi media pembelajaran bagi pelajar, mahasiswa, dan penggiat teknologi yang tertarik dalam bidang:
a. Embedded systems (sistem tertanam)
b. Otomasi rumah tangga
c. Robotika dan sensor
d. Desain mekanik dan prototyping

Melalui alat ini, pengguna dapat memahami bagaimana sistem teknologi bekerja secara terintegrasi, mulai dari logika program, pengolahan data sensor, hingga respons aktuator. Proyek ini juga dapat menjadi bahan tugas akhir atau proyek kolaboratif antar bidang (elektro, mesin, dan desain produk).

9. Mengembangkan Konsep Smart Pet Feeder sebagai Bagian dari Sistem Rumah Pintar (Smart Home). Dengan basis mikrokontroler dan sensor, alat ini memiliki potensi untuk dikembangkan menjadi bagian dari ekosistem rumah pintar. Dalam pengembangan jangka panjang, alat dapat diintegrasikan dengan:
a. Modul Wi-Fi seperti ESP8266 untuk kontrol jarak jauh.
b. Aplikasi smartphone untuk monitoring dan kontrol real-time.
c. Sistem notifikasi atau peringatan ketika pakan habis atau terjadi error.

Tujuan ini mendukung visi untuk menciptakan lingkungan rumah tangga yang lebih cerdas, efisien, dan ramah terhadap pemilik hewan peliharaan.

10. Meningkatkan Kesejahteraan Hewan Peliharaan Melalui Teknologi. Dengan sistem pemberi pakan yang terjadwal, presisi, dan otomatis, alat ini dapat berkontribusi terhadap:
a. Pola makan yang lebih stabil dan seimbang bagi kucing.
b. Pengurangan risiko obesitas akibat pemberian pakan berlebih.
c. Menghindari stres pada hewan karena keterlambatan pemberian pakan saat pemilik tidak di rumah.
11. Mendukung Gaya Hidup Modern dan Mobilitas Tinggi Pemilik Hewan. Dengan meningkatnya mobilitas masyarakat urban dan meningkatnya aktivitas harian yang padat, alat Cat Pour dirancang untuk menjadi bagian dari solusi penunjang gaya hidup modern. Banyak pemilik kucing yang harus bekerja di luar rumah selama berjam-jam atau bahkan sering bepergian dalam jangka waktu tertentu. Oleh karena itu, alat ini bertujuan untuk:
a. Menyediakan sistem pemberian pakan yang andal dan konsisten, sehingga pemilik tidak perlu khawatir akan keterlambatan atau kelupaan memberi makan.
b. Mengurangi kecemasan pemilik saat meninggalkan rumah, karena alat dapat beroperasi mandiri sesuai dengan jadwal yang ditentukan.
c. Membantu pemilik yang memiliki lebih dari satu hewan peliharaan untuk mengatur jadwal makan tanpa perlu melakukannya secara manual.

12. Menumbuhkan Kesadaran akan Pentingnya Perawatan Hewan Peliharaan secara Bertanggung Jawab. Tujuan lain dari alat ini adalah sebagai alat edukasi dan advokasi untuk mendorong pemilik hewan agar lebih bertanggung jawab terhadap kesehatan dan kesejahteraan peliharaan mereka. Alat ini menunjukkan bahwa dengan bantuan teknologi, perawatan hewan bisa dilakukan secara konsisten dan tepat.

Beberapa poin penting:

a. Memberi pemahaman bahwa pemberian pakan tidak boleh berlebihan atau asal-asalan.
b. Mendorong pemilik untuk memperhatikan jadwal makan yang konsisten.
c. Menjadi bukti bahwa perhatian terhadap hewan bisa tetap diberikan walau pemilik sedang tidak berada di rumah.
13. Mendorong Penggunaan Teknologi Tepat Guna di Rumah Tangga. Proyek ini bertujuan untuk menunjukkan bagaimana konsep teknologi tepat guna dapat diimplementasikan pada level rumah tangga. Tidak semua teknologi harus mahal dan kompleks; dengan komponen sederhana, biaya terjangkau, dan perakitan yang mudah, alat ini dapat menjadi contoh bagaimana teknologi bisa dimanfaatkan secara efisien untuk kebutuhan sehari-hari.

Tujuannya meliputi:

a. Menyederhanakan proses otomatisasi rumah tangga untuk hewan peliharaan.
b. Menginspirasi masyarakat untuk mengembangkan alat serupa sesuai kebutuhan masing-masing.
c. Menjadi sarana pembelajaran untuk pengembangan teknologi berbiaya rendah namun fungsional.
14. Memperluas Peluang Usaha di Bidang Teknologi dan Perawatan Hewan. Dengan melihat tren meningkatnya kepemilikan hewan peliharaan di kalangan masyarakat menengah, proyek ini juga diarahkan sebagai prototipe awal yang bisa dikembangkan menjadi produk komersial. Tujuan jangka panjang dari alat Cat Pour adalah:
a. Membuka peluang usaha rumahan atau UMKM di bidang teknologi pet care.
b. Memberikan ide bisnis kepada siswa, mahasiswa, atau teknisi yang ingin memulai usaha di bidang inovasi fungsional.
c. Menjadi contoh bahwa proyek berbasis Arduino dan komponen dasar elektronik bisa dikembangkan menjadi produk bernilai jual.

15. Menekan Dampak Lingkungan dari Produksi Massal Alat Elektronik. Dalam merancang Cat Pour, digunakan bahan kayu triplek dan komponen minimalis untuk mengurangi jejak karbon serta dampak lingkungan dari pembuatan alat. Tujuan ini bertujuan untuk:
a. Mengurangi ketergantungan terhadap plastik dan bahan kimia lain yang lazim digunakan dalam produk elektronik massal.
b. Mendorong penggunaan material yang dapat didaur ulang atau dibongkar-pasang dengan mudah.
c. Meningkatkan kesadaran akan pentingnya desain berkelanjutan (sustainable design) dalam pengembangan alat berbasis teknologi.
16. Membangun Dasar untuk Pengembangan Sistem IoT (Internet of Things). Walaupun prototipe awal berbasis Arduino Nano tanpa koneksi internet, proyek ini dirancang dengan memperhitungkan kemungkinan ekspansi ke sistem IoT. Tujuannya mencakup:
a. Membangun fondasi sistem pemberi pakan berbasis cloud, dengan fitur pemantauan jarak jauh.
b. Mengembangkan dashboard berbasis web atau aplikasi yang dapat terhubung dengan alat secara real time.
c. Menyediakan data log pemberian pakan dan deteksi keberadaan kucing secara historis yang bisa digunakan untuk analisis kebiasaan makan.
17. Mengembangkan Sistem yang Adaptif dan Cerdas (Smart Feeding System). Selain pemberian pakan berdasarkan waktu dan berat, alat ini dapat dikembangkan menjadi sistem adaptif yang mampu mempelajari pola makan kucing secara otomatis menggunakan pendekatan machine learning. Dalam jangka panjang, tujuan pengembangan meliputi:
a. Memanfaatkan data dari sensor untuk menyesuaikan jumlah dan waktu pemberian pakan sesuai kebiasaan hewan.
b. Mengidentifikasi perilaku abnormal, seperti berkurangnya nafsu makan, sebagai indikator kesehatan hewan.
c. Menyesuaikan sistem dengan berbagai jenis pakan dan ukuran kucing.
18. Menjadi Wadah Kolaborasi Antar Disiplin Ilmu. Proyek ini berpotensi menjadi proyek kolaboratif antara berbagai disiplin ilmu seperti teknik elektro, mekatronika, teknik mesin, desain produk, kedokteran hewan, hingga ilmu komputer. Tujuan ini meliputi:
a. Mendorong kegiatan kolaboratif antara pelajar, peneliti, dan praktisi dalam mengembangkan solusi nyata.

b. Menjadi bahan tugas akhir, penelitian terapan, atau proyek sosial berbasis teknologi.
c. Mempertemukan keilmuan teoritis dengan penerapan praktis dalam satu sistem alat fungsional.
19. Meningkatkan User Experience (Pengalaman Pengguna) dalam Mengelola Hewan. Alat ini juga bertujuan untuk menghadirkan pengalaman pengguna yang menyenangkan dan mudah dalam mengelola kebutuhan makan kucing. Dengan antarmuka sederhana, alat ini bisa digunakan oleh berbagai kalangan, termasuk:
a. Orang tua yang ingin melibatkan anak-anak dalam mengurus hewan.
b. Lansia yang sudah sulit bergerak atau lupa waktu.
c. Pemula yang baru pertama kali memelihara kucing.
20. Meningkatkan Nilai Kreativitas dan Inovasi di Lingkungan Pendidikan. Terakhir, alat ini juga bertujuan untuk menjadi proyek inspiratif yang mendorong kreativitas dan inovasi di sekolah atau kampus. Dalam berbagai perlombaan robotika, teknologi terapan, atau karya ilmiah remaja, alat ini bisa:
a. Memberikan ide inovatif berbasis masalah nyata di masyarakat.
b. Menunjukkan bagaimana teknologi sederhana dapat menjawab kebutuhan sehari-hari.
c. Menginspirasi siswa untuk lebih menyukai dunia STEM (Science, Technology, Engineering, and Mathematics).

## 1.4 Manfaat

### 1. Mempermudah Pemilik Kucing dalam Memberi Pakan Secara Otomatis dan Terjadwal. Alat

ini memungkinkan pemilik kucing untuk menjadwalkan pemberian pakan secara otomatis berdasarkan waktu yang ditentukan sebelumnya. Dengan sistem otomatisasi ini, pengguna tidak perlu lagi repot memberi makan secara manual setiap hari, terutama bagi mereka yang memiliki jadwal kerja padat atau sering bepergian. Hal ini dapat mengurangi stres dan kekhawatiran pemilik terhadap kesehatan dan kenyamanan hewan peliharaannya.

### 2. Menjaga Pola Makan yang Konsisten untuk Kesehatan Kucing. Konsistensi dalam pola makan

merupakan hal penting untuk menjaga kesehatan hewan peliharaan, terutama dalam menghindari obesitas atau kekurangan nutrisi. Dengan alat ini, kucing akan menerima pakan dalam jumlah dan waktu yang teratur, yang secara tidak langsung membantu menjaga berat badan ideal dan kondisi metabolisme tubuhnya tetap stabil. Hal ini penting karena kucing yang makan tidak teratur lebih rentan mengalami masalah pencernaan dan gangguan perilaku.

### 3. Mengurangi Pemborosan dan Menghemat Pakan. Alat ini dirancang untuk mengeluarkan

pakan dalam jumlah tertentu menggunakan sensor berat (load cell), sehingga takaran pakan dapat diatur secara presisi. Ini membantu menghindari pemborosan akibat pemberian pakan yang berlebihan. Selain itu, pakan yang diberikan secara berlebih bisa cepat basi atau tercecer, terutama jika kucing tidak menghabiskannya dalam satu waktu. Penghematan ini bukan hanya berdampak positif dari sisi biaya, tapi juga dari sisi efisiensi penggunaan sumber daya.

### 4. Memberikan Sarana Pembelajaran Nyata bagi Pelajar dan Mahasiswa. Cat Pour dapat

digunakan sebagai media pembelajaran interaktif dalam bidang teknik elektro, mekatronika, otomasi, dan teknologi informasi. Mahasiswa dapat mempelajari bagaimana sebuah sistem otomatis dibangun mulai dari perancangan mekanik, pemrograman mikrokontroler, hingga integrasi sensor dan aktuator. Proyek ini juga memperkenalkan konsep sistem tertanam (embedded system) yang umum digunakan dalam industri modern.

5. Bisa Dijadikan Tugas Akhir atau Penelitian Terapan. Banyak perguruan tinggi atau sekolah kejuruan mendorong mahasiswanya untuk mengembangkan proyek yang aplikatif. Alat Cat Pour sangat cocok dijadikan topik tugas akhir karena mencakup banyak aspek: pemrograman, desain mekanik, integrasi elektronik, pengukuran presisi, dan rekayasa perangkat lunak. Selain itu, alat ini juga membuka peluang untuk penelitian lebih lanjut seperti pengembangan smart system, pemrosesan data sensor, atau penggunaan algoritma pembelajaran mesin untuk adaptasi kebiasaan hewan.
6. Melatih Keterampilan Multidisipliner dalam Satu Proyek. Proyek Cat Pour melibatkan banyak keterampilan seperti:
- Desain mekanik: Membuat rangka dan struktur yang ergonomis dan fungsional.
- | Elektronika | dasar: | Menghubungkan | sensor | dan | aktuator.
- | Pemrograman | mikrokontroler: | Membuat | algoritma | logika | kerja | alat.
- | Pengujian | dan | kalibrasi: | Menyesuaikan | sistem | agar | berjalan | stabil.

Dengan demikian, proyek ini sangat efektif untuk melatih kemampuan multidisipliner yang sangat dibutuhkan dalam dunia kerja industri 4.0.

### 7. Contoh Nyata Penerapan Otomatisasi Berbasis Arduino. Arduino sebagai platform open-

source telah banyak digunakan dalam pengembangan sistem otomatisasi. Namun, masih banyak orang yang hanya mengenalnya di tingkat dasar. Alat ini dapat menjadi contoh konkret bagaimana Arduino dapat digunakan dalam membangun sistem otomatisasi yang fungsional, relevan dengan kehidupan nyata, dan dapat dikembangkan lebih lanjut untuk berbagai kebutuhan lain.

### 8. Menjadi Inspirasi Inovasi Alat Otomatis Lainnya. Keberhasilan alat Cat Pour dalam

menyelesaikan masalah pemberian pakan kucing dapat menginspirasi terciptanya alat-alat otomatisasi lainnya, seperti:

- | Dispenser | air | otomatis | untuk | hewan.
- | Sistem | pembersih | litter | box | otomatis.
- | Alat | monitoring | kesehatan | hewan | berbasis | sensor.

Dengan membangkitkan semangat inovasi ini, masyarakat dapat berkontribusi dalam pengembangan solusi rumah tangga berbasis teknologi yang murah dan mudah dibuat.

### 9. Mendukung Penggunaan Material Ramah Lingkungan. Penggunaan kayu triplek sebagai

bahan utama rangka alat menunjukkan komitmen terhadap keberlanjutan lingkungan. Kayu triplek mudah didaur ulang, dapat diperoleh secara lokal, dan memiliki jejak karbon lebih rendah dibandingkan bahan sintetis seperti plastik. Dengan ini, Cat Pour mengedepankan prinsip green design dalam proyek Fteknologi rumah tangga.

10. Meningkatkan Kesadaran Akan Desain yang Berkelanjutan. Manfaat lain dari alat ini adalah menanamkan pemahaman bahwa desain suatu produk tidak hanya dilihat dari fungsinya saja, tetapi juga dari dampak jangka panjangnya terhadap lingkungan, biaya produksi, dan efisiensi penggunaan energi. Dengan pendekatan desain berkelanjutan, pengguna dan perancang dapat belajar mempertimbangkan siklus hidup produk sejak tahap perancangan.

### 11. Menumbuhkan Jiwa Kewirausahaan Teknologi. Prototipe seperti Cat Pour berpotensi untuk

dikembangkan menjadi produk komersial yang dipasarkan kepada masyarakat luas. Hal ini membuka peluang usaha di bidang teknologi rumah tangga untuk hewan peliharaan, terutama karena pasar pet care terus berkembang dari tahun ke tahun. Dengan memahami bagaimana sistem ini dirancang dan bekerja, seseorang dapat membangun lini produk sendiri dan menjadi wirausahawan teknologi yang kreatif.

### 12. Memberikan Nilai Tambah pada Dunia Pendidikan Vokasional. Alat ini sangat cocok

digunakan di sekolah menengah kejuruan (SMK), politeknik, maupun balai pelatihan kerja (BLK) karena relevan dengan kurikulum vokasi berbasis praktik. Para siswa bisa belajar melalui proyek nyata yang memberikan pemahaman menyeluruh dari hulu ke hilir—dari teori dasar, praktik perakitan, hingga pemrograman dan pengujian sistem. Ini akan memberikan nilai tambah pada kompetensi lulusan di bidang teknik dan teknologi terapan.

### 13. Membantu Komunitas Pencinta Hewan dalam Merawat Kucing Jalanan. Selain untuk pemilik

kucing pribadi, alat ini juga bermanfaat bagi relawan atau komunitas yang merawat kucing liar atau kucing komunitas. Dengan alat ini, pakan dapat diberikan pada waktu dan jumlah yang konsisten tanpa harus selalu hadir di lokasi, sehingga sangat membantu dalam manajemen logistik pemberian pakan secara massal di tempat penampungan atau shelter.

### 14. Menjadi Media Edukasi STEM yang Menyenangkan. Cat Pour juga dapat digunakan sebagai

media pengenalan konsep STEM (Science, Technology, Engineering, Mathematics) bagi siswa sekolah dasar atau menengah dalam bentuk workshop atau kegiatan ekstrakurikuler. Karena alat ini bersifat interaktif dan bermanfaat langsung dalam kehidupan sehari-hari, siswa akan lebih mudah memahami prinsip ilmiah dan teknis dalam bentuk yang menyenangkan.

### 15. Memperkenalkan Konsep Smart Home dan Otomatisasi Domestik. Dengan integrasi sensor

dan logika pemrograman, alat ini dapat menjadi pengantar konsep rumah pintar (smart home) kepada masyarakat umum. Meskipun alat ini hanya menyasar satu fungsi, yakni pemberian pakan kucing, prinsip kerjanya mirip dengan sistem smart home lain seperti pengatur suhu otomatis, lampu sensor gerak, atau pintu otomatis. Hal ini dapat mendorong adopsi teknologi otomasi yang lebih luas di rumah-rumah.

16. Mengajarkan Etika Perawatan Hewan yang Konsisten. Salah satu manfaat sosial dari alat ini adalah menumbuhkan kesadaran bahwa perawatan hewan bukan hanya soal memberi makan sesekali, tapi tentang konsistensi dan tanggung jawab jangka panjang. Dengan teknologi ini, pemilik hewan belajar menghargai rutinitas dan kebutuhan hewan sebagai makhluk hidup yang juga membutuhkan perhatian.
17. Menjadi Model Awal untuk Sistem Berbasis Data dan Analitik. Penggunaan sensor load cell dan ultrasonik memberikan data real-time yang dapat dicatat dan dianalisis lebih lanjut. Dalam pengembangan berikutnya, data ini dapat digunakan untuk:

- | Melihat | kebiasaan | makan | kucing.
- | Mendeteksi | perubahan | perilaku.
- | Memberikan | laporan | kepada | dokter | hewan | bila | diperlukan.

Manfaat ini membuka jalan untuk alat pemantau kesehatan hewan berbasis data di masa depan.

### 18. Mengembangkan Kemandirian Teknologi Lokal. Dengan merancang alat dari awal

menggunakan komponen yang tersedia di pasar lokal (seperti Arduino, servo motor, load cell), masyarakat dapat belajar untuk tidak bergantung pada teknologi impor yang mahal dan kompleks. Ini menciptakan budaya teknologi mandiri di kalangan pelajar, mahasiswa, maupun komunitas DIY (Do It Yourself).

### 19. Mempercepat Transformasi Digital dalam Kehidupan Rumah Tangga. Alat Cat Pour bisa

dianggap sebagai bagian dari proses transformasi digital dalam kehidupan rumah tangga, di mana aktivitas manual beralih ke otomatisasi yang terprogram. Semakin banyak rumah tangga yang menggunakan sistem seperti ini, semakin dekat masyarakat pada ekosistem smart living.

20. Menginspirasi Gerakan Inovasi Sosial dan Teknologi. Proyek ini tidak hanya menciptakan alat, tetapi juga dapat menjadi pemicu gerakan inovasi sosial dan teknologi, di mana individu atau komunitas mulai merancang solusi atas masalah sehari-hari dengan teknologi yang dapat diakses semua kalangan. Cat Pour membuktikan bahwa inovasi tidak harus mahal atau kompleks—cukup dimulai dari kepedulian terhadap masalah kecil yang nyata di sekitar kita.

### 21. Meningkatkan Inklusivitas Teknologi untuk Masyarakat Umum. Salah satu hambatan

terbesar dalam adopsi teknologi oleh masyarakat umum adalah kesan bahwa teknologi itu rumit dan mahal. Alat Cat Pour membuktikan bahwa siapa pun—termasuk pemilik hewan peliharaan di daerah dengan akses terbatas terhadap teknologi canggih—dapat memiliki perangkat otomatis yang sederhana namun fungsional. Inklusivitas ini mendorong partisipasi lebih luas dari berbagai kalangan masyarakat dalam era digital.

### 22. Mendukung Gaya Hidup Modern yang Serba Cepat dan Mobile. Dalam era urbanisasi dan

mobilitas tinggi, banyak orang yang memiliki pekerjaan dengan jam kerja panjang, sering bepergian keluar kota, atau tinggal sendiri. Alat ini sangat sesuai dengan gaya hidup modern tersebut, karena mampu menggantikan tugas rutin yang kecil namun penting—seperti memberi makan kucing—dengan sistem otomatis yang dapat diandalkan.

### 23. Memberikan Rasa Tenang dan Aman bagi Pemilik Hewan. Pemilik kucing sering kali merasa

cemas meninggalkan hewan peliharaan mereka sendirian di rumah. Dengan alat Cat Pour, pemilik bisa lebih tenang karena tahu bahwa kucing mereka tetap mendapatkan makan secara teratur dan dalam jumlah yang tepat. Rasa aman ini berdampak langsung pada kesejahteraan mental pemilik, terutama saat mereka sedang bepergian jauh.

### 24. Dapat Disesuaikan untuk Hewan Lain (Modifikasi Fungsi). Meskipun awalnya dirancang

untuk kucing, prinsip kerja alat ini dapat dengan mudah dimodifikasi untuk hewan peliharaan lain seperti anjing kecil, kelinci, atau bahkan ayam. Cukup dengan menyesuaikan ukuran wadah, jenis pakan, dan volume keluaran, alat ini bisa menjadi sistem pemberian pakan multi-spesies yang fleksibel dan efisien.

### 25. Mendorong Budaya Berbagi Inovasi Open-Source. Dengan memanfaatkan platform terbuka

seperti Arduino dan komponen umum seperti load cell dan servo, Cat Pour mendorong semangat berbagi inovasi antar komunitas. Pengguna dapat mengakses, memodifikasi, dan menyebarkan skematik atau kode sumber alat ini secara bebas, yang mempercepat penyebaran teknologi dan peningkatan versi oleh komunitas global.

### 26. Meningkatkan Kesadaran Terhadap Pentingnya Dokumentasi Proyek. Dalam proses

perancangan dan implementasi Cat Pour, dokumentasi menjadi bagian penting. Baik itu dokumentasi teknis, wiring diagram, pseudocode, hingga laporan hasil uji, semua melatih pengguna untuk tertib dalam mendokumentasikan pekerjaan mereka. Ini adalah kebiasaan baik yang sangat dihargai dalam dunia akademik maupun industri.

27. Potensi Integrasi dengan Teknologi Internet of Things (IoT). Meski pada tahap awal alat ini bersifat semi-otomatis, pengembangan ke depan bisa diarahkan pada integrasi dengan IoT. Contohnya:
- | Pemilik | bisa | memantau | jumlah | pakan | dari | jarak | jauh.
- | Menyesuaikan | jadwal | makan | lewat | aplikasi.
- | Menerima | notifikasi | saat | pakan | hampir | habis.

Dengan potensi ini, Cat Pour bisa menjadi awal dari sistem rumah pintar yang saling terhubung.

28. Melatih Pemikiran Logis dan Sistematis dalam Pemecahan Masalah. Proyek seperti Cat Pour mengajarkan bagaimana merancang solusi dari awal dengan pendekatan sistematis. Mulai dari mengidentifikasi masalah, merancang alur logika, memilih komponen, menyusun program, hingga menguji sistem secara menyeluruh. Ini memberikan pengalaman langsung dalam menerapkan metode rekayasa untuk menyelesaikan masalah nyata.

### 29. Menyediakan Alternatif Ramah Disabilitas untuk Pemilik Kucing. Alat ini bisa sangat

membantu pemilik kucing yang mengalami keterbatasan fisik (misalnya lansia atau disabilitas tangan) dalam memberi makan hewan peliharaan mereka. Dengan otomatisasi, mereka tidak perlu membuka wadah pakan atau menuang pakan secara manual, yang dapat meningkatkan kemandirian dan kenyamanan hidup mereka.

30. Menjadi Portofolio Kuat untuk Karier di Bidang Teknologi. Bagi pelajar, mahasiswa, atau hobiis teknologi, menyelesaikan proyek seperti Cat Pour dapat dijadikan portofolio nyata. Dokumentasi lengkap proyek ini bisa ditampilkan saat melamar kerja, magang, atau beasiswa, menunjukkan bahwa mereka tidak hanya memahami teori, tetapi mampu menerapkannya dalam bentuk nyata dan bermanfaat.

### 31. Memberikan Peluang Kolaborasi Multidisiplin

Pembuatan Cat Pour membuka ruang kolaborasi antara berbagai disiplin ilmu:

- | Teknik | elektro | & | mekatronika: | untuk | sistem | kendali | dan | sensorik.
- | Teknik | mesin: | untuk | perancangan | mekanik | wadah | dan | aktuator.
- | Desain | produk: | untuk | ergonomi | dan | estetika.
- Teknik informatika: untuk pengembangan logika dan potensi antarmuka aplikasi.
- | Lingkungan: | untuk | memilih | material | yang | ramah | lingkungan.

Kolaborasi ini tidak hanya memperkaya hasil akhir, tetapi juga membangun keterampilan kerja tim lintas disiplin.

### 32. Dapat Diintegrasikan dengan Kamera atau Sistem Pemantauan Visual. Pengembangan

lanjutan dari Cat Pour dapat mencakup integrasi dengan kamera mini atau modul AI vision, seperti ESP32-CAM. Ini akan memungkinkan alat mendeteksi kehadiran kucing secara visual dan mengidentifikasi apakah hewan sudah makan atau belum. Dengan demikian, sistem bisa menjadi lebih pintar dan adaptif terhadap kebiasaan unik tiap kucing.

### 33. Mengurangi Ketergantungan pada Alat Impor Berharga Mahal. Di pasar, terdapat banyak

alat pemberi pakan otomatis buatan luar negeri yang harganya cukup tinggi dan sering tidak sesuai dengan kebutuhan lokal. Dengan membuat sendiri, pengguna bisa menyesuaikan fitur dengan kebutuhan dan kemampuan finansial masing-masing. Hal ini juga memperkuat daya saing produk teknologi lokal buatan anak bangsa.

### 34. Menjadi Media Workshop atau Pelatihan Teknologi untuk Masyarakat. Banyak komunitas

atau instansi yang menyelenggarakan pelatihan keterampilan teknologi. Cat Pour adalah proyek ideal untuk dijadikan materi workshop karena:

- | Mudah | dipahami.
- | Dapat | diselesaikan | dalam | beberapa | sesi.
- | Hasil | akhirnya | bermanfaat | langsung.

Pelatihan ini bisa menyasar pelajar, guru, komunitas pecinta hewan, atau masyarakat umum yang tertarik belajar teknologi praktis.

### 35. Mempromosikan Perawatan Hewan yang Bertanggung Jawab. Penggunaan alat ini

menunjukkan bahwa pemilik kucing memperhatikan aspek waktu, kuantitas, dan konsistensi dalam merawat hewannya. Ini dapat menjadi contoh bagi masyarakat luas tentang bagaimana tanggung jawab terhadap hewan peliharaan dapat dijalankan secara modern dan efisien.

### 36. Mendorong Penerapan Prinsip Daur Ulang dan Rekayasa Ulang. Komponen dan struktur dari

alat Cat Pour dapat dengan mudah dibongkar dan digunakan ulang untuk keperluan lain. Misalnya, sensor ultrasonik dapat digunakan untuk sistem parkir otomatis, load cell untuk timbangan digital, dan servo untuk proyek robotika. Dengan demikian, alat ini menjadi sarana pembelajaran berkelanjutan yang tidak berhenti pada satu fungsi saja.

### 37. Mendorong Pengembangan Dokumentasi Visual (YouTube, Blog, eBook)

Karena sifatnya aplikatif dan menarik, proyek ini sangat cocok untuk didokumentasikan secara visual. Mahasiswa, pelajar, atau content creator teknologi dapat membuat:

- | Tutorial | YouTube | step-by-step.
- | Panduan | eBook | open | source.
- | Blog | yang | menjelaskan | logika | kerja | dan | pemrograman.

Ini akan memperkaya ekosistem pembelajaran digital yang kini menjadi semakin penting.

### 38. Memberikan Dampak Ekonomi Melalui Produk DIY (Do It Yourself). Alat seperti Cat Pour

dapat diproduksi dan dijual dalam bentuk kit DIY (paket rakit sendiri). Ini membuka peluang bisnis rumahan berbasis edukasi, di mana pembeli bisa mendapatkan perangkat sekaligus pengalaman belajar merakitnya sendiri. Segmentasi ini cocok untuk komunitas homeschool, pecinta kucing, dan penggemar DIY.

39. Meningkatkan Apresiasi Terhadap Karya Teknologi Lokal. Ketika masyarakat melihat bahwa alat seperti ini dapat dibuat dengan alat sederhana dan komponen lokal, akan tumbuh rasa apresiasi terhadap potensi anak bangsa. Ini akan memperkuat semangat untuk mendukung produk-produk dalam negeri, yang penting dalam mewujudkan kemandirian teknologi nasional.

### 40. Menjadi Cikal Bakal Ekosistem Teknologi Perawatan Hewan di Indonesia. Dengan semakin

banyaknya proyek seperti Cat Pour, bukan tidak mungkin Indonesia bisa membangun ekosistem produk teknologi yang mendukung kesejahteraan hewan. Dari alat makan otomatis, pemantauan kesehatan, hingga sistem pengawasan kandang, semua bisa tumbuh dari proyek kecil yang sederhana namun berdampak besar.

## BAB II TINJAUAN PUSTAKA

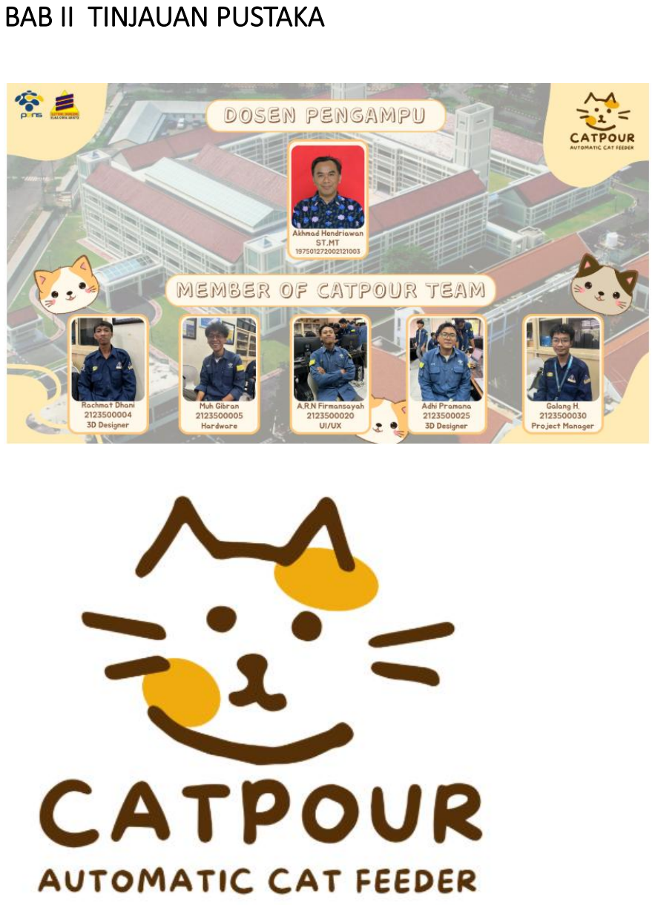
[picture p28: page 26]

## 2.1 Mikrokontroler Arduino Nano

Mikrokontroler Arduino Nano adalah sebuah papan mikrokontroler kecil berbasis chip ATmega328P yang dirancang untuk mengendalikan sistem elektronik secara otomatis. Ukurannya yang compact membuat Arduino Nano sangat cocok digunakan dalam proyek yang memerlukan perangkat elektronik berukuran ringkas, seperti prototipe sistem tertanam dan aplikasi Internet of Things (IoT). Arduino Nano memiliki berbagai pin input/output digital dan analog yang memungkinkan penghubungan dengan berbagai sensor dan aktuator, serta dapat diprogram menggunakan perangkat lunak Arduino IDE untuk menjalankan berbagai fungsi sesuai kebutuhan proyek.

### 2.1.1 Pengertian Arduino Nano

Mikrokontroler merupakan komponen elektronik yang memiliki fungsi sebagai pusat pengendali dalam berbagai sistem elektronik dan sistem tertanam (embedded system). Salah satu mikrokontroler yang banyak digunakan dalam proyek-proyek elektronik modern adalah Arduino Nano. Arduino Nano adalah mikrokontroler berbasis ATmega328P yang berukuran kecil namun memiliki kemampuan yang cukup lengkap untuk berbagai aplikasi.

Arduino Nano dirancang agar mudah digunakan dan diintegrasikan dengan berbagai sensor dan modul tambahan. Dengan dimensi fisik yang ringkas (sekitar 45 mm × 18 mm), Arduino Nano sangat cocok untuk aplikasi yang membutuhkan ruang terbatas, seperti perangkat portabel dan sistem Internet of Things (IoT). Arduino Nano menyediakan 14 pin digital input/output, 8 pin input analog, serta beberapa fitur komunikasi seperti UART, SPI, dan I2C yang memungkinkan pertukaran data dengan perangkat lain secara efisien.

Selain itu, Arduino Nano bekerja pada tegangan operasi 5 Volt dan menggunakan clock berkecepatan 16 MHz yang memberikan kecepatan pemrosesan yang memadai untuk berbagai kebutuhan pemrograman. Modul ini juga dilengkapi dengan memori flash sebesar 32 KB untuk menyimpan program, serta SRAM dan EEPROM untuk penyimpanan data sementara maupun permanen.

Dalam penggunaannya, Arduino Nano berfungsi untuk menerima sinyal dari sensor, memproses data berdasarkan program yang telah dibuat, dan mengirimkan sinyal output untuk mengendalikan aktuator atau perangkat lain. Kemudahan pemrograman melalui Arduino IDE dan dukungan komunitas yang luas menjadikan Arduino Nano pilihan ideal dalam pengembangan sistem prototipe maupun produk akhir.

Dengan karakteristik tersebut, Arduino Nano sangat sesuai digunakan dalam berbagai proyek seperti sistem otomatisasi, pengendalian perangkat elektronik, sistem monitoring, dan aplikasi

IoT. Oleh karena itu, pada penelitian atau proyek ini, Arduino Nano dipilih sebagai mikrokontroler utama untuk mengendalikan dan memproses data dari sensor-sensor yang digunakan.

### 2.1.2 Spesifikasi Teknis Arduino Nano

Tabel di bawah ini merangkum spesifikasi teknis utama dari Arduino Nano:

Spesifikasi | Nilai
Mikrokontroler | ATmega328P
Tegangan Operasional | 5 V

Tegangan Input (disarankan) 7–12 V

Tegangan Input (batas) | 6–20 V
Jumlah Pin Digital I/O | 14 (6 pin mendukung PWM)
Jumlah Pin Analog Input | 8
Jumlah Pin PWM | 6 (D3, D5, D6, D9, D10, D11)
Kecepatan Clock | 16 MHz
Memori Flash | 32 KB (2 KB digunakan oleh bootloader)
SRAM | 2 KB
EEPROM | 1 KB
Arsitektur | AVR 8-bit
Antarmuka Pemrograman | USB Mini-B
Ukuran | 45 mm × 18 mm

Berat | Sekitar 7 gram

Arduino Nano juga dilengkapi dengan bootloader, yang memungkinkan pemrograman langsung melalui kabel USB tanpa memerlukan perangkat tambahan seperti ISP programmer.

### 2.1.3 Keunggulan Arduino Nano

Arduino Nano memiliki berbagai keunggulan yang membuatnya sangat diminati, baik oleh pemula maupun profesional:

1. Ukuran | | | Kompak
Dengan bentuk yang kecil dan ringan, Arduino Nano sangat cocok digunakan pada proyek-proyek yang membutuhkan efisiensi ruang, seperti perangkat portabel, drone, dan sistem
otomatisasi | rumah | skala | kecil.
2. Kompatibilitas | Perangkat | Lunak
Karena menggunakan ATmega328P, Arduino Nano sepenuhnya kompatibel dengan Arduino Uno dari segi pemrograman. Semua sketsa (program) yang ditulis untuk Arduino
Uno | dapat | dijalankan | pada | Arduino | Nano | tanpa | perubahan | berarti.
3. Konsumsi | Daya | Rendah
Arduino Nano memiliki konsumsi daya yang relatif rendah, terutama saat dikonfigurasi untuk sleep mode. Ini sangat penting dalam aplikasi yang mengandalkan baterai atau
sumber | daya | terbatas.
4. Integrasi | Mudah | dengan | Breadboard
Arduino Nano dapat dipasang langsung ke breadboard, sehingga mempermudah proses
eksperimen | dan | pengembangan | rangkaian | elektronik.
5. Harga | Terjangkau
Dibandingkan dengan papan mikrokontroler lain, Arduino Nano memiliki harga yang cukup ekonomis, menjadikannya pilihan ideal untuk prototipe dan proyek skala kecil.

### 2.1.4 Penerapan Arduino Nano dalam Proyek Cat Pour

Dalam proyek Cat Pour, sebuah alat pemberi pakan kucing otomatis berbasis mikrokontroler, Arduino Nano berperan sebagai otak utama dari sistem. Sistem ini melibatkan beberapa komponen, seperti:

- Sensor ultrasonik HC-SR04: untuk mendeteksi keberadaan kucing di depan tempat makan.
- Load cell + modul HX711: untuk mengukur berat pakan yang sudah dikeluarkan.
- Servo motor: untuk membuka dan menutup katup tempat pakan secara presisi.

Arduino Nano menerima input dari sensor ultrasonik yang mendeteksi gerakan atau keberadaan kucing. Ketika kucing terdeteksi dan waktu pemberian pakan sudah sesuai, Arduino akan memeriksa berat pakan yang tersedia menggunakan data dari load cell. Jika pakan belum mencukupi, Arduino Nano akan mengaktifkan motor servo untuk membuka katup dan menuangkan pakan.

Seluruh logika pengambilan keputusan, komunikasi antar sensor, dan kontrol motor dijalankan sepenuhnya oleh Arduino Nano berdasarkan kode program yang ditanamkan ke dalamnya.

Selain itu, Arduino Nano juga dapat dikembangkan lebih lanjut untuk mendukung fitur Internet of Things (IoT) dengan menambahkan modul komunikasi seperti ESP8266 atau HC-05 Bluetooth, sehingga pengguna dapat memantau dan mengendalikan alat dari jarak jauh melalui smartphone.

### 2.1.5 Diagram Koneksi Sistem

Berikut adalah ilustrasi koneksi antar komponen dalam sistem Cat Pour (deskripsi tanpa gambar):

1. Pin D2 dan D3: Terhubung ke trigger dan echo sensor ultrasonik HC-SR04.
2. Pin | A0: | Terhubung | ke | modul | HX711 | (data | dari | load | cell).

3. Pin | D9: | Terhubung | ke | motor | servo | untuk | pengontrol | katup.
4. VCC | dan | GND: | Menyediakan | daya | ke | semua | sensor | dan | modul.
5. Port USB: Digunakan untuk pemrograman dan juga dapat menyuplai daya dari adaptor atau komputer.

### 2.1.6 Perbandingan Arduino Nano dengan Mikrokontroler Lain

Parameter | Arduino Nano | Arduino Uno | ESP32 | Raspberry Pi Pico
Ukuran | Kecil (45x18 mm) | Sedang (68x53 mm) | Kecil–Sedang | Kecil
Mikrokontroler | ATmega328P | ATmega328P | Tensilica Xtensa dual-core

RP2040

Clock Speed | 16 MHz | 16 MHz | Hingga 240 MHz Hingga 133
MHz
Jumlah I/O | 22 (14 D, 8 A) | 20 (14 D, 6 A) | >30 | 26 GPIO
WiFi/Bluetooth | Tidak | ada | (perlu
| modul tambahan) | Tidak ada | Ada | Tidak ada

Tegangan
Operasional
5V | 5V | 3.3V | 3.3V

Kemudahan
Pemakaian
Sangat mudah | Sangat mudah | Sedikit | lebih
| | kompleks

Mudah

Harga | Rendah | Sedang | Bervariasi | Rendah

Berdasarkan tabel di atas, Arduino Nano lebih unggul dari segi ukuran dan kemudahan pemakaian pada sistem sederhana, sementara ESP32 unggul dalam hal performa dan konektivitas. Pemilihan papan mikrokontroler disesuaikan dengan kebutuhan sistem; dalam kasus Cat Pour, Arduino Nano sudah mencukupi dan optimal.

### 2.1.7 Tantangan dan Solusi dalam Penggunaan Arduino Nano

Beberapa tantangan umum saat menggunakan Arduino Nano dalam proyek meliputi:

1. Keterbatasan | | | | Memori
Memori Flash hanya 32 KB dapat menjadi kendala jika proyek melibatkan pustaka (library) yang besar. Solusinya adalah mengoptimalkan kode, menghapus library yang tidak perlu,
dan | menggunakan | fungsi | yang | efisien.
2. Jumlah | Pin | Terbatas
Pada proyek yang membutuhkan banyak input/output, jumlah pin Arduino Nano dapat menjadi kurang. Solusi: menggunakan expander I/O seperti IC 74HC595 atau multiplexer.
3. Keterbatasan | Tegangan | dan | Arus
Setiap pin hanya mampu menyuplai arus hingga 40 mA. Untuk mengontrol beban besar seperti motor DC atau aktuator, perlu digunakan driver atau relay eksternal.

### 2.1.8 Potensi Pengembangan

Arduino Nano memiliki potensi untuk dikembangkan lebih lanjut dalam sistem Cat Pour dengan fitur seperti:

1. Real-time Clock (RTC): Untuk menjadwalkan pemberian pakan secara otomatis
berdasarkan | | | waktu.
2. Tampilan LCD/OLED: Untuk menampilkan informasi waktu, berat pakan, atau notifikasi.

Konektivitas IoT: Menggunakan modul WiFi (ESP8266) agar alat bisa dikontrol dari jarak jauh
melalui | aplikasi | atau | dashboard | web.

3. Fitur suara atau lampu indikator: Memberikan notifikasi kepada pengguna atau kucing saat pakan akan keluar.

### 2.1.9 Kesimpulan

Arduino Nano adalah solusi mikrokontroler yang efisien, ringkas, dan mudah digunakan untuk berbagai proyek otomatisasi skala kecil. Dalam proyek Cat Pour, Arduino Nano berperan sebagai pusat kendali yang mengatur proses pemberian pakan secara otomatis berdasarkan data dari sensor dan logika sistem. Dengan spesifikasi yang cukup mumpuni, konsumsi daya rendah, serta kemudahan integrasi, Arduino Nano sangat cocok untuk aplikasi seperti alat pemberi pakan otomatis, khususnya yang membutuhkan dimensi kecil dan sistem sederhana.

## 2.2 Sensor Ultrasonik HC-SR04

Sensor Ultrasonik HC-SR04 adalah sensor elektronik yang digunakan untuk mengukur jarak suatu objek dengan menggunakan gelombang ultrasonik. Sensor ini bekerja berdasarkan prinsip pantulan gelombang suara (seperti sonar), dan umum digunakan dalam berbagai aplikasi, seperti robotika, sistem parkir otomatis, alat ukur jarak, dan proyek berbasis mikrokontroler seperti Arduino.

Komponen dan Cara Kerja:

Sensor HC-SR04 terdiri dari dua bagian utama:

1. Transmitter (Trig): Mengirimkan gelombang ultrasonik (dengan frekuensi sekitar 40 kHz).
2. Receiver (Echo): Menerima gelombang pantul dari objek di depan sensor.

Langkah Kerja:

1. Mengirim Sinyal: Pin Trig diberi pulsa selama 10 mikrodetik, yang menyebabkan sensor
mengirimkan | 8 | gelombang | ultrasonik.
2. Menerima Pantulan: Gelombang ini akan memantul jika mengenai objek, lalu ditangkap
oleh | Echo.

3. Menghitung Jarak: Waktu dari saat gelombang dikirim hingga diterima kembali digunakan
untuk | menghitung | jarak | objek | menggunakan | rumus:
Jarak (cm)=Waktu Tempuh (μs)×0,03432\text{Jarak (cm)} = \frac{\text{Waktu Tempuh
(μs)} | \times | 0{,}0343}{2}Jarak | (cm)=2Waktu | Tempuh | (μs)×0,0343
(0,0343 cm/μs adalah kecepatan suara di udara; dibagi 2 karena sinyal menempuh jarak dua arah: ke objek dan kembali).

## 2.3 Load Cell dan Modul HX711

Load cell adalah sensor atau alat ukur yang digunakan untuk mengukur gaya atau berat suatu benda. Umumnya, load cell digunakan dalam timbangan digital, sistem pemantauan beban, dan alat-alat industri yang membutuhkan pengukuran berat secara akurat.

Cara Kerja Load Cell (Secara Umum)

Load cell bekerja dengan cara mengubah tekanan atau gaya menjadi sinyal listrik. Saat beban diletakkan pada load cell:

1. Bagian logam di dalamnya akan sedikit melengkung karena tekanan dari beban.
2. Di bagian logam ini terpasang komponen kecil bernama strain gauge (semacam kawat tipis).
3. Saat logam melengkung, strain gauge ikut tertarik atau tertekan → menyebabkan
perubahan | resistansi | listrik.
4. Perubahan | resistansi | ini | menghasilkan | perubahan | tegangan | listrik.
5. Tegangan tersebut sangat kecil dan perlu diperkuat agar bisa dibaca oleh alat seperti Arduino (biasanya dengan bantuan modul HX711).

Modul HX711 adalah modul ADC (Analog to Digital Converter) 24-bit yang dirancang khusus untuk membaca sinyal dari sensor Load Cell.

Modul ini digunakan untuk:

- | Memperkuat | sinyal | listrik | yang | sangat | kecil | dari | load | cell.
- Mengubah sinyal analog tersebut menjadi data digital agar bisa dibaca oleh mikrokontroler seperti Arduino, ESP32, atau Raspberry Pi.

Cara Kerja Sederhana HX711:

1. Load | cell | menghasilkan | tegangan | kecil | saat | menerima | beban.
2. HX711 memperkuat tegangan tersebut dan mengubahnya menjadi data digital.
3. Data | digital | dikirim | ke | Arduino | melalui | pin | DT | dan | SCK.
4. Arduino mengolah data tersebut menjadi nilai berat (misalnya gram atau kilogram).

### 2.2.1 Prinsip Kerja

Sensor ultrasonik HC-SR04 merupakan salah satu jenis sensor jarak yang paling umum digunakan dalam sistem berbasis mikrokontroler karena kemudahannya dalam implementasi dan biayanya yang rendah. Sensor ini bekerja berdasarkan prinsip pemantulan gelombang suara di luar jangkauan pendengaran manusia, yang dikenal sebagai gelombang ultrasonik. HC-SR04 menggunakan frekuensi gelombang ultrasonik sebesar 40 kHz, yang dikirimkan melalui komponen pemancar (transmitter) menuju suatu objek di depannya. Ketika gelombang ini mengenai objek, gelombang akan dipantulkan kembali dan diterima oleh komponen penerima (receiver).

Proses pengukuran jarak dimulai ketika mikrokontroler memberikan sinyal pemicu (trigger) ke pin TRIG dari sensor. Sinyal ini berupa pulsa logika tinggi (HIGH) dengan durasi minimal 10 mikrodetik. Setelah menerima sinyal ini, sensor akan secara otomatis mengirimkan delapan gelombang ultrasonik berfrekuensi 40 kHz. Sensor kemudian menunggu pantulan gelombang tersebut ditangkap oleh receiver. Ketika pantulan diterima, pin ECHO pada sensor akan berubah menjadi HIGH selama durasi waktu tempuh gelombang dari sensor ke objek dan kembali.

Waktu yang diperlukan gelombang untuk kembali ke sensor dicatat oleh mikrokontroler dan digunakan untuk menghitung jarak menggunakan rumus:

Pembagian dengan dua dilakukan karena waktu tempuh yang dicatat adalah waktu bolak-balik dari sensor ke objek dan kembali ke sensor.

Sensor HC-SR04 sangat andal dalam mengukur jarak dengan presisi hingga milimeter, dan memiliki banyak aplikasi dalam berbagai sistem otomatisasi, termasuk robotika, sistem keamanan, serta sistem monitoring otomatis seperti proyek Cat Pour.

### 2.2.2 Spesifikasi Teknis

Sensor HC-SR04 memiliki spesifikasi teknis sebagai berikut:

Parameter | Nilai
Tegangan Operasi | 5V DC
Arus Operasi | <15 mA
Frekuensi Operasi | 40 kHz
Jarak Deteksi | 2 cm – 400 cm
Akurasi | ±3 mm
Sudut Deteksi | ±15 derajat
Waktu Respons | <50 ms
Ukuran Fisik | ±45 mm x 20 mm x 15 mm
Interface | TTL Level Trigger & Echo

Kondisi Operasional Suhu: -15°C hingga +70°C

Sensor ini menggunakan antarmuka digital sederhana, yakni pin TRIG untuk memicu pengiriman gelombang dan pin ECHO sebagai output durasi waktu pantulan. Kombinasi ini membuatnya mudah diintegrasikan dengan berbagai jenis mikrokontroler termasuk Arduino Nano, Uno, Mega, ESP32, dan lainnya.

Sudut deteksi sensor yang relatif sempit (±15 derajat) memberikan keuntungan dalam hal akurasi karena hanya objek yang berada tepat di depannya yang akan terdeteksi. Ini menjadikannya sangat cocok untuk aplikasi yang membutuhkan deteksi yang fokus dan tidak menyebar, seperti dalam proyek Cat Pour.

### 2.2.3 Aplikasi dalam Sistem Cat Pour

Dalam proyek "Cat Pour", sensor HC-SR04 memiliki dua peran penting yang menunjang fungsionalitas alat pemberi pakan kucing otomatis agar bekerja dengan cerdas dan efisien. Adapun dua aplikasi utamanya adalah sebagai berikut:

A. Deteksi Kehadiran Kucing

Salah satu fitur penting dari sistem Cat Pour adalah kemampuan untuk mendeteksi kehadiran kucing di depan alat. Sensor HC-SR04 ditempatkan menghadap ke area mangkuk makan, sehingga dapat mengukur apakah ada objek (dalam hal ini kucing) dalam jarak tertentu. Ketika sensor mendeteksi objek dalam jarak misalnya 5 hingga 30 cm, sistem menginterpretasikan bahwa kucing sedang berada di depan alat dan mungkin sedang meminta makan.

Dengan logika ini, alat hanya akan mengeluarkan makanan jika benar-benar ada kucing yang sedang berada di tempat makan. Ini memberikan efisiensi luar biasa karena pakan tidak akan dikeluarkan secara sia-sia ketika mangkuk kosong atau ketika kucing tidak sedang berada di lokasi. Selain itu, pendekatan ini juga mendukung konsep berkelanjutan dengan mengurangi pemborosan makanan dan menjaga kebersihan area makan kucing.

B. Deteksi Keberadaan Mangkuk

Selain digunakan untuk mendeteksi kehadiran kucing, sensor HC-SR04 juga dapat difungsikan untuk memastikan bahwa mangkuk makanan berada pada posisinya yang benar. Hal ini sangat penting, karena jika mangkuk bergeser, miring, atau tidak berada di tempatnya, makanan yang dikeluarkan bisa tumpah ke lantai, menyebabkan pemborosan dan menimbulkan potensi masalah kebersihan.

Dengan menempatkan sensor pada sudut strategis, Arduino Nano dapat melakukan pengecekan otomatis terhadap keberadaan wadah makanan sebelum perintah pemberian pakan dijalankan. Jika sensor tidak mendeteksi pantulan dalam jarak yang telah ditentukan (misalnya > 50 cm), maka sistem mengasumsikan bahwa mangkuk tidak berada di tempatnya dan proses pemberian pakan akan dibatalkan atau ditunda.

C. Integrasi Sensor dengan Mikrokontroler dan Komponen Lain

Sensor HC-SR04 bekerja secara sinergis dengan komponen lain seperti servo motor, load cell, dan mikrokontroler Arduino Nano. Alur sistemnya secara umum adalah sebagai berikut:

1. Arduino mengirimkan sinyal ke pin TRIG untuk memicu pengukuran.

2. Sensor mengukur jarak dan mengirimkan durasi waktu pantulan melalui pin ECHO.
3. Arduino menghitung jarak menggunakan rumus konversi waktu ke centimeter.
4. Jika jarak yang dideteksi sesuai dengan kriteria kehadiran kucing dan mangkuk:
- Arduino memerintahkan servo untuk membuka pintu pakan.
- Load cell mulai mengukur berat makanan yang keluar.
- Ketika berat makanan mencapai target, servo ditutup.

Proses ini menjadikan sistem Cat Pour sebagai alat pemberi pakan otomatis yang berbasis pada kondisi aktual di sekitar alat, bukan hanya berbasis waktu seperti banyak alat sejenis.

Dengan menggunakan sensor HC-SR04, Cat Pour tidak hanya menjadi alat pemberi makan, tetapi juga sebuah sistem pintar yang mampu merespons kondisi nyata secara real time. Hal ini meningkatkan kenyamanan bagi pemilik hewan peliharaan dan memperkuat nilai teknologi dalam kehidupan sehari-hari.

### 2.3.1 Prinsip Kerja Load Cell

Load cell adalah sensor yang digunakan untuk mengukur gaya atau berat dengan mengubahnya menjadi sinyal listrik. Tipe load cell yang digunakan dalam Cat Pour adalah strain gauge, yang memiliki sensitivitas tinggi terhadap perubahan tekanan.

### 2.3.2 Modul HX711

HX711 adalah modul ADC (Analog to Digital Converter) dengan resolusi tinggi yang dirancang untuk bekerja dengan load cell. Modul ini memiliki kemampuan untuk membaca sinyal dalam skala mikrovolt, sangat cocok untuk mendeteksi perubahan berat kecil seperti makanan kucing.

### 2.3.3 Fungsi dalam Cat Pour

Load cell berfungsi untuk mengukur berat makanan yang keluar dari wadah utama ke mangkuk. Data ini kemudian digunakan oleh Arduino untuk menghentikan pemberian pakan saat berat yang ditargetkan telah tercapai.

## 2.4 Servo Motor

### 2.4.1 Pengertian Servo

Servo motor adalah aktuator berjenis motor DC yang telah dilengkapi dengan sistem kontrol posisi. Servo memiliki kelebihan berupa gerakan presisi, respons cepat, dan mudah dikendalikan dengan sinyal PWM.

Servo motor adalah perangkat elektromekanis yang berfungsi sebagai aktuator putar, dirancang dengan sistem kontrol umpan balik tertutup (closed-loop) untuk mengatur posisi sudut poros output secara presisi. Biasanya, servo motor terdiri dari motor DC, serangkaian gear untuk meningkatkan torsi, potensiometer sebagai sensor posisi, dan rangkaian kontrol yang mengatur gerakan berdasarkan sinyal masukan. Sinyal kontrol ini umumnya berupa sinyal PWM (Pulse Width Modulation), di mana lebar pulsa menentukan posisi sudut yang diinginkan.

Keunggulan utama servo motor meliputi kemampuan untuk menghasilkan gerakan yang presisi, respons yang cepat terhadap perubahan sinyal kontrol, dan kemudahan dalam pengendalian melalui sinyal PWM. Selain itu, servo motor mampu mempertahankan posisi dengan stabil meskipun terdapat gangguan atau beban tambahan, berkat sistem umpan balik yang terus-menerus memantau dan menyesuaikan posisi poros output. Hal ini menjadikan servo motor sangat ideal untuk aplikasi yang memerlukan kontrol posisi yang akurat, seperti dalam robotika, sistem otomasi industri, dan perangkat kendali presisi lainnya

### 2.4.2 Spesifikasi

### 1. Tegangan kerja: 4.8 – 6.0 V

### 2. Sudut rotasi: 0°–180°

### 3. Waktu respons cepat (≈0.1 s/60°)

### 4. Torsi: 1.8–3 kg/cm tergantung tipe

### 2.4.3 Fungsi dalam Cat Pour

Servo digunakan untuk menggerakkan pintu mekanik pada saluran keluaran pakan. Saat diberi sinyal oleh Arduino, servo membuka saluran untuk mengalirkan pakan, dan menutupnya setelah berat pakan mencukupi berdasarkan pembacaan dari load cell.

## 2.5 Kayu Triplek sebagai Material Rangka

### 2.5.1 Karakteristik Kayu Triplek

Triplek adalah produk kayu olahan berbentuk lembaran yang terdiri dari beberapa lapisan veneer yang direkatkan dengan arah serat yang saling bersilangan. Karakteristiknya adalah:

1. Tahan terhadap perubahan bentuk
2. Lebih kuat dibanding MDF
3. Ringan dan mudah dikerjakan

4. Dapat dipotong dan dibentuk dengan alat pertukangan dasar

### 2.5.2 Alasan Pemilihan

Kayu triplek digunakan sebagai bahan rangka karena memberikan keseimbangan antara kekuatan, ketersediaan, biaya, dan kemudahan pengerjaan. Bentuk dan ukuran yang tercantum dalam gambar teknik (tinggi 400 mm, lebar 200 mm, kedalaman 162 mm) memungkinkan kayu triplek untuk dibentuk menjadi struktur vertikal dan luncuran dengan sudut yang ergonomis bagi kucing.

### 2.5.3 Ketersediaan dan Efisiensi Biaya

Kayu triplek merupakan salah satu material konstruksi yang paling mudah ditemukan di pasaran Indonesia. Ketersediaannya yang melimpah di toko-toko bangunan lokal menjadikannya pilihan utama bagi banyak pengrajin dan kontraktor. Selain itu, triplek tersedia dalam berbagai ukuran dan ketebalan, memungkinkan fleksibilitas dalam pemilihan sesuai kebutuhan proyek.

Dari segi biaya, triplek menawarkan efisiensi yang signifikan. Dibandingkan dengan kayu solid atau material olahan lainnya, triplek memiliki harga yang lebih terjangkau tanpa mengorbankan kualitas strukturalnya. Hal ini menjadikannya solusi ekonomis untuk berbagai aplikasi, mulai dari pembuatan furnitur hingga konstruksi bangunan semi permanen.

### 2.5.4 Kemudahan dalam Proses Pengerjaan

Salah satu keunggulan utama kayu triplek adalah kemudahannya dalam proses pengerjaan. Material ini dapat dipotong, dibor, dan dibentuk dengan alat pertukangan dasar, seperti gergaji tangan, bor listrik, dan pahat. Tekstur permukaannya yang halus juga memudahkan dalam proses finishing, seperti pengecatan atau pelapisan dengan veneer.

Kemudahan ini tidak hanya mempercepat waktu pengerjaan, tetapi juga memungkinkan pengrajin untuk menyesuaikan desain sesuai kebutuhan spesifik proyek. Misalnya, dalam pembuatan struktur vertikal dan luncuran untuk hewan peliharaan, triplek dapat dibentuk dengan sudut dan ukuran yang ergonomis, memastikan kenyamanan dan keamanan bagi hewan tersebut.

### 2.5.5 Ketahanan dan Keandalan Struktural

Triplek memiliki struktur berlapis dengan arah serat yang bersilangan, memberikan kekuatan dan stabilitas yang superior dibandingkan dengan material kayu olahan lainnya. Struktur ini membuat triplek tahan terhadap tekanan, lenturan, dan beban berat, menjadikannya pilihan ideal untuk aplikasi struktural

Selain itu, triplek memiliki ketahanan yang baik terhadap perubahan suhu dan kelembaban, mengurangi risiko deformasi seperti melengkung atau retak. Beberapa jenis triplek bahkan dilengkapi dengan lapisan pelindung tambahan yang meningkatkan ketahanannya terhadap air dan serangan hama, seperti rayap. Dengan perawatan yang tepat, struktur yang terbuat dari triplek dapat bertahan dalam jangka waktu yang lama, memberikan nilai investasi yang tinggi bagi pemiliknya.

## 2.6 Konsep Otomatisasi dan IoT Sederhana

### 2.6.1 Otomatisasi Rumah Tangga

Perkembangan teknologi telah memungkinkan rumah tangga mengintegrasikan berbagai perangkat otomatis seperti smart lamp, smart lock, dan smart feeder. Cat Pour adalah bentuk otomatisasi yang bertujuan meningkatkan efisiensi dan kenyamanan dalam memelihara hewan.

Perkembangan teknologi telah memungkinkan rumah tangga mengintegrasikan berbagai perangkat otomatis seperti smart lamp, smart lock, dan smart feeder. Salah satu inovasi dalam otomatisasi perawatan hewan peliharaan adalah Cat Pour, sebuah sistem pemberian makan otomatis yang dirancang untuk meningkatkan efisiensi dan kenyamanan dalam memelihara hewan.

Cat Pour memungkinkan pemilik hewan untuk mengatur jadwal makan secara presisi, mengontrol porsi makanan, dan bahkan memantau aktivitas hewan melalui kamera yang terintegrasi. Beberapa model smart feeder, seperti IT Smart Feeder PE02, dilengkapi dengan fitur kamera Full HD, voice notes, dan push notification yang membantu pemilik tetap terhubung dengan hewan peliharaan mereka meskipun sedang tidak berada di rumah . Selain itu, fitur seperti Anti Food Dampness menjaga makanan tetap segar, sementara kapasitas penyimpanan yang besar memungkinkan pemberian makan otomatis selama beberapa hari tanpa perlu pengisian ulang

Dengan integrasi teknologi ini, Cat Pour tidak hanya mempermudah rutinitas pemberian makan, tetapi juga memberikan ketenangan pikiran bagi pemilik hewan, memastikan bahwa kebutuhan nutrisi hewan peliharaan terpenuhi secara konsisten dan tepat waktu. Inovasi semacam ini mencerminkan bagaimana teknologi dapat berperan penting dalam meningkatkan kualitas hidup baik bagi hewan peliharaan maupun pemiliknya.

### 2.6.2 Potensi IoT

Meskipun Cat Pour tidak terkoneksi internet pada tahap awal, konsep ini sangat memungkinkan untuk ditingkatkan menjadi perangkat IoT dengan tambahan modul WiFi seperti ESP8266. Dengan begitu, pemilik dapat memonitor dan mengendalikan alat dari jarak jauh melalui ponsel.

### 2.6.3 Integrasi dengan Aplikasi dan Platform Pintar

CatPour memiliki potensi untuk diintegrasikan dengan berbagai aplikasi dan platform pintar, seperti Blynk, Senric Pro, atau Google Assistant. Dengan menggunakan modul Wi-Fi seperti ESP8266, pengguna dapat mengontrol dan memantau perangkat dari jarak jauh melalui aplikasi di smartphone. Misalnya, proyek DIY yang menggunakan ESP8266 dan aplikasi Blynk memungkinkan pemilik hewan untuk mengatur jadwal pemberian makan dan memantau status makanan secara real-time.

Integrasi dengan platform seperti Google Assistant juga memungkinkan kontrol suara, memberikan kenyamanan tambahan bagi pengguna. Dengan demikian, CatPour tidak hanya berfungsi sebagai alat pemberi makan otomatis, tetapi juga sebagai bagian dari ekosistem rumah pintar yang lebih luas.

### 2.6.4 Personalisasi dan Interaksi Langsung dengan Hewan Peliharaan

Fitur personalisasi, seperti perekaman pesan suara, memungkinkan pemilik hewan untuk berinteraksi langsung dengan hewan peliharaan mereka, bahkan saat tidak berada di rumah. Beberapa feeder pintar, seperti PETKIT YumShare, memungkinkan pengguna merekam pesan suara hingga 20 detik yang akan diputar saat makanan disajikan, membantu hewan merasa lebih nyaman dan terhubung dengan pemiliknya.

Selain itu, fitur notifikasi melalui aplikasi dapat memberitahu pemilik tentang berbagai kondisi, seperti makanan yang hampir habis, gangguan pada perangkat, atau kebutuhan penggantian desiccant bag, memastikan pemilik selalu mendapatkan informasi terkini tentang kondisi perangkat dan kebutuhan hewan peliharaan mereka.

### 2.6.5 Keamanan dan Ketahanan Sistem

Keamanan dan ketahanan sistem merupakan aspek penting dalam desain CatPour. Beberapa feeder pintar dilengkapi dengan sistem anti-macet yang mencegah makanan tersumbat, serta desain kedap udara untuk menjaga kesegaran makanan. Misalnya, PETKIT YumShare menggunakan teknologi anti-blokir dan sistem penguncian ganda untuk memastikan makanan tetap segar dan tidak terkontaminasi.

Selain itu, fitur cadangan daya, seperti baterai darurat, memastikan perangkat tetap berfungsi meskipun terjadi pemadaman listrik, memberikan ketenangan pikiran bagi pemilik hewan peliharaan.

### 2.6.6 Potensi Pengembangan di Masa Depan

CatPour memiliki potensi untuk dikembangkan lebih lanjut dengan menambahkan fitur-fitur canggih, seperti integrasi dengan kamera pengawas, analisis pola makan hewan, dan pengingat kesehatan. Dengan menambahkan modul kamera, pemilik dapat memantau aktivitas hewan peliharaan secara langsung dan memastikan mereka makan dengan baik. Analisis data pola makan dapat membantu dalam mengidentifikasi perubahan perilaku makan yang mungkin menandakan masalah kesehatan.

Integrasi dengan platform kesehatan hewan peliharaan juga memungkinkan pengingat untuk vaksinasi, pemeriksaan rutin, dan kebutuhan medis lainnya, menjadikan CatPour sebagai alat yang tidak hanya memberikan makanan, tetapi juga mendukung kesehatan dan kesejahteraan hewan peliharaan secara keseluruhan.

## 2.7 Studi Terdahulu dan Proyek Serupa

### 2.7.1 Proyek Open Source Pakan Otomatis

Beberapa komunitas seperti Arduino.cc dan Instructables telah membagikan berbagai proyek feeder otomatis yang umumnya berbasis Arduino Uno dan ESP32. Namun, kebanyakan menggunakan bahan plastik, 3D printing, atau botol bekas. “Cat Pour” menawarkan pendekatan berbeda dengan kayu sebagai bahan utama dan ukuran yang telah diatur secara presisi.

### 2.7.2 Penelitian Akademik

Terdapat penelitian dari perguruan tinggi yang membahas otomatisasi pakan ternak berbasis IoT, namun belum banyak yang fokus pada skala rumah tangga dan hewan peliharaan khususnya kucing. Proyek ini menjembatani kebutuhan praktis dengan pendekatan ilmiah dan teknik.

### 2.7.3 Studi Kasus: Penerapan IoT dalam Pemberian Pakan Kucing

Penelitian oleh Nurul Aulia Dewi dari STMIK "AMIKBANDUNG" mengembangkan alat pemberi pakan kucing otomatis berbasis IoT yang dapat dipantau melalui aplikasi Android. Sistem ini memungkinkan penjadwalan pemberian pakan dan pemantauan berat pakan secara real-time, dengan tingkat keberhasilan pengeluaran pakan sebesar 95,62% dan rata-rata error 4,38% atau selisih sekitar 1-3 gram dari berat porsi pakan yang dimasukkan pengguna.

Studi lain oleh Muhammad Aksyal Bambang Suseno dari Universitas Pendidikan Indonesia merancang pet feeder berbasis IoT yang dikontrol melalui aplikasi Android. Alat ini memiliki fitur pemberian pakan manual dan penjadwalan, dengan rata-rata output pakan 83,2 gram untuk mode manual dan 66,9 gram untuk mode penjadwalan.

### 2.7.4 Integrasi Sensor dan Aplikasi dalam Sistem Feeder

Lilik Hari Santoso dan tim dari Sekolah Tinggi Teknologi Texmaco mengembangkan tempat pakan kucing otomatis berbasis IoT yang dikendalikan oleh mikrokontroler Wemos D1, motor servo, dan sensor load cell. Sistem ini terintegrasi dengan aplikasi Blynk untuk monitoring dan kontrol jarak jauh, memungkinkan pengukuran berat pakan dan pengendalian pemberian pakan sesuai kondisi yang ditetapkan pengguna.

Penelitian oleh Legina Praba Ayu dan tim mengembangkan perangkat pemberi makan kucing otomatis berbasis IoT yang menggunakan mikrokontroler NodeMCU ESP8266, dua buah load cell, dan aplikasi Blynk. Alat ini dilengkapi dengan kamera pemantau yang memungkinkan pemilik melihat keadaan sekitar alat dan hewan peliharaan secara real-time melalui aplikasi.

### 2.7.5 Penggunaan Platform Komunikasi Alternatif

Putri Ayu Rengganis Suganda dan Ari Mulyoto dari Universitas Pamulang merancang alat pemberi pakan hewan peliharaan otomatis yang dikendalikan melalui Telegram Bot. Sistem ini menggunakan mikrokontroler NodeMCU ESP8266 dan motor servo untuk mengoperasikan pemberian pakan, memberikan alternatif platform komunikasi selain aplikasi khusus.

### 2.7.6 Pengembangan Prototipe Feeder Berbasis IoT

Penelitian oleh Mohammad Fahrul Fahruddin dan tim dari Universitas Islam Kadiri mengembangkan prototipe alat pemberi makan kucing otomatis berbasis IoT. Sistem ini memungkinkan pengaturan jadwal makan dan pemantauan jumlah makanan yang tersisa, dengan rata-rata selisih pembacaan sensor load cell sebesar 1,2 gram dibandingkan timbangan digital.

### 2.7.7 Implementasi Sistem Monitoring dan Penjadwalan

Muhammad Rizky Imam P. dari Telkom University merancang dan mengimplementasikan sistem monitoring dan pemberi pakan kucing otomatis berbasis Android. Sistem ini menggunakan algoritma penjadwalan non-preemptive dan mikrokontroler NodeMCU yang terintegrasi dengan smartphone Android, memungkinkan kontrol dan monitoring pakan kucing dari jarak jauh.

### 2.7.8 Evaluasi Kinerja Sistem Pemberi Pakan Otomatis

Penelitian oleh Muhammad Angga Ramadhan dan tim dari Telkom University mengevaluasi kinerja sistem monitoring dan pemberi pakan kucing otomatis berbasis IoT. Sistem ini menggunakan mikrokontroler ESP32, sensor ultrasonik HCSR04, dan motor servo, dengan pengujian selama 3 hari menunjukkan bahwa alat berfungsi dengan baik sesuai jadwal yang ditentukan, dengan rata-rata kesalahan sebesar 11,2% dalam jumlah pakan yang dikeluarkan.

### 2.7.9 Integrasi Platform Blynk dalam Sistem Feeder

Richwen Canady dan tim dari Pradita University merancang alat pemberi makan hewan peliharaan pintar menggunakan mikrokontroler ESP32 dan platform Blynk. Perangkat ini menawarkan fitur pemberian makan otomatis dan manual jarak jauh, serta pemantauan real-time makanan yang tersedia melalui aplikasi mobile Blynk.

### 2.7.10 Perbandingan dengan Proyek CatPour

Dari berbagai studi dan proyek yang telah dibahas, dapat disimpulkan bahwa mayoritas sistem pemberi pakan otomatis menggunakan bahan plastik atau hasil cetak 3D sebagai material utama. Dalam hal ini, CatPour menawarkan pendekatan yang berbeda dengan menggunakan kayu sebagai bahan utama, memberikan estetika yang lebih alami dan integrasi yang lebih baik dengan lingkungan rumah. Selain itu, CatPour dirancang dengan ukuran yang telah diatur secara presisi, memastikan kenyamanan dan keamanan bagi hewan peliharaan.

Dalam aspek teknologi, CatPour memiliki potensi untuk diintegrasikan dengan berbagai platform pintar dan aplikasi, seperti Blynk atau Google Assistant, memungkinkan kontrol dan monitoring dari jarak jauh. Dengan penambahan modul WiFi seperti ESP8266, sistem ini dapat ditingkatkan menjadi perangkat IoT yang lebih canggih, memberikan kemudahan dan kenyamanan bagi pemilik hewan peliharaan dalam mengatur jadwal makan dan memantau aktivitas hewan mereka.

## BAB III PEMROGRAMAN CATPOUR

## 3.1 Pendahuluan

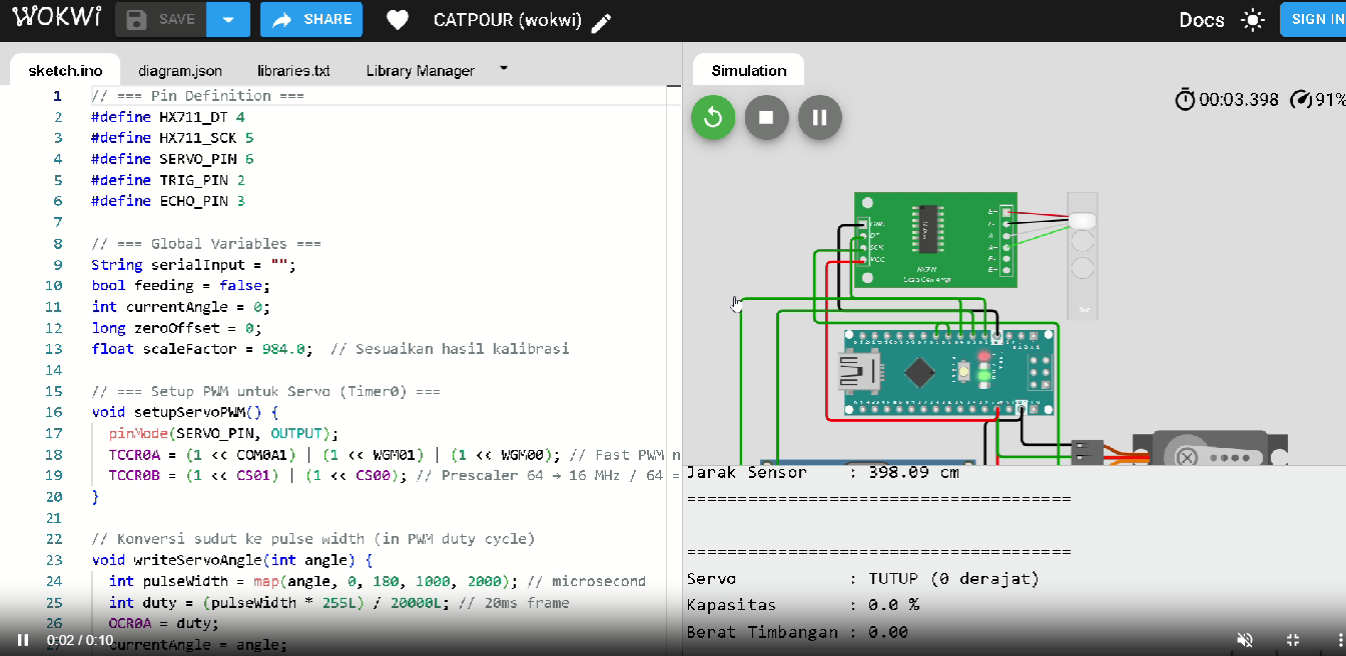
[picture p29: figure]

Pemrograman adalah jantung dan otak dari sistem otomatisasi CatPour, menjadi fondasi utama yang memungkinkan seluruh fungsi perangkat berjalan cerdas dan otonom. Tanpa kode program yang terstruktur dan logis, CatPour hanyalah kumpulan komponen elektronik pasif. Dalam proyek inovatif ini, mikrokontroler Arduino Nano dipilih sebagai pusat kendali utama, bertindak layaknya seorang konduktor yang menyelaraskan setiap instrumen dalam orkestra. Arduino Nano bertanggung jawab penuh dalam mengatur semua proses secara sekuensial dan paralel, mulai dari menerima dan menginterpretasikan masukan data dari berbagai sensor hingga menerjemahkan data tersebut menjadi serangkaian instruksi spesifik yang kemudian dikirimkan kepada aktuator untuk melakukan tindakan fisik.

Untuk mewujudkan fungsionalitas kompleks ini, bahasa pemrograman C/C++ digunakan. Pilihan ini sangat strategis mengingat keunggulan C/C++ dalam hal efisiensi, kontrol tingkat rendah terhadap perangkat keras, dan performa tinggi yang sangat dibutuhkan dalam sistem embedded. Seluruh kode program dikembangkan, dikompilasi, dan diunggah melalui platform Arduino IDE (Integrated Development Environment) yang ramah pengguna. Arduino IDE menyediakan lingkungan yang intuitif bagi pengembang untuk menulis kode, mengelola library, serta memfasilitasi proses debugging dan upload ke mikrokontroler.

Fokus utama pemrograman CatPour adalah untuk menciptakan sebuah sistem yang mampu memberikan pakan secara otomatis, terjadwal, dan terukur. Ini bukan sekadar mekanisme on/off sederhana; program harus mampu menentukan kapan pakan harus diberikan (berdasarkan jadwal), berapa banyak pakan yang harus dikeluarkan (berdasarkan berat), dan kondisi lingkungan seperti apa yang harus dipenuhi (misalnya, keberadaan mangkuk). Lebih jauh lagi, pengembangan kode sangat mempertimbangkan efisiensi energi agar perangkat dapat beroperasi dalam jangka waktu yang lama dengan sumber daya terbatas. Keandalan kerja sistem juga menjadi prioritas, memastikan bahwa setiap proses berjalan konsisten dan tidak mudah mengalami crash atau bug. Terakhir, ketepatan logika sistem menjadi fundamental; setiap keputusan yang diambil oleh mikrokontroler harus didasarkan pada alur berpikir yang presisi dan tidak ambigu, sehingga CatPour dapat berfungsi secara efektif dalam berbagai skenario dan memberikan pengalaman terbaik bagi hewan peliharaan serta pemiliknya. Melalui pemrograman yang cermat, CatPour berevolusi dari sekadar prototipe menjadi solusi pakan otomatis yang cerdas dan dapat diandalkan.

## 3.2 Struktur Umum Program

Kode program yang menggerakkan sistem CatPour dirancang dengan struktur yang modular dan terorganisir, mempermudah pemahaman, pengembangan, dan pemeliharaan. Secara umum, program dibagi menjadi beberapa bagian utama yang masing-masing memiliki peran spesifik dalam menjalankan otomatisasi pemberian pakan:

Inisialisasi Perangkat Keras

Bagian pertama dari kode program didedikasikan untuk inisialisasi perangkat keras. Ini adalah fondasi di mana seluruh sistem akan dibangun. Pada tahap ini, semua pin input/output (I/O) yang terhubung ke sensor dan aktuator didefinisikan dengan jelas. Misalnya, pin digital untuk sensor ultrasonik HC-SR04 (Trigger dan Echo), pin untuk komunikasi dengan modul HX711 load cell (Data dan Clock), serta pin Pulse Width Modulation (PWM) untuk servo motor akan dideklarasikan. Selain itu, bagian ini juga mencakup pengaturan awal untuk komunikasi serial, yang sangat berguna untuk debugging dan pemantauan data secara real-time melalui Serial Monitor di Arduino IDE. Pendefinisian yang rapi di awal kode ini memastikan bahwa mikrokontroler mengetahui lokasi dan fungsi setiap komponen yang terhubung.

Fungsi setup()

Fungsi setup() adalah blok kode yang hanya akan dieksekusi satu kali ketika Arduino Nano pertama kali dihidupkan atau di-reset. Ini adalah tempat yang ideal untuk melakukan persiapan awal yang krusial bagi operasi sistem. Di dalam fungsi setup(), komunikasi serial akan diinisialisasi dengan baud rate tertentu (misalnya, Serial.begin(9600)), memungkinkan Arduino untuk mengirimkan data diagnostik ke komputer. Selanjutnya, konfigurasi pin dilakukan, di mana setiap pin yang telah didefinisikan sebelumnya akan diatur apakah berfungsi sebagai input (untuk sensor) atau output (untuk aktuator). Contohnya, pin Trigger HC-SR04 akan diatur sebagai output, sedangkan pin Echo-nya sebagai input. Yang tidak kalah penting, kalibrasi awal sensor juga sering dilakukan di sini, terutama untuk load cell yang memerlukan penyesuaian offset atau scale agar pembacaan berat akurat sejak awal sistem beroperasi. Semua langkah dalam setup() ini memastikan bahwa sistem siap untuk menjalankan logika utamanya.

### 2.8 Fungsi setup() dalam Sistem CatPour

Dalam pengembangan sistem otomatisasi seperti CatPour, fungsi setup() pada platform Arduino memainkan peran krusial dalam memastikan bahwa semua komponen perangkat keras dan perangkat lunak siap beroperasi dengan optimal sejak awal. Fungsi ini hanya dijalankan sekali, yaitu saat Arduino pertama kali dinyalakan atau di-reset, dan bertanggung jawab untuk melakukan inisialisasi awal sistem.

### 2.8.1 Inisialisasi Komunikasi Serial

Langkah pertama dalam fungsi setup() adalah menginisialisasi komunikasi serial antara Arduino dan komputer atau perangkat lain. Hal ini memungkinkan pengiriman data diagnostik, debugging, atau informasi lainnya selama pengembangan dan pengujian sistem. Contohnya, dengan menggunakan perintah Serial.begin(9600);, Arduino akan mulai berkomunikasi pada baud rate 9600 bps.

### 2.8.2 Konfigurasi Pin Input dan Output

Setelah komunikasi serial diinisialisasi, langkah berikutnya adalah mengatur mode kerja setiap pin yang digunakan dalam sistem. Pin-pin ini dapat dikonfigurasi sebagai input atau output tergantung pada peranannya:

- Sensor Ultrasonik HC-SR04: Pin Trigger dikonfigurasi sebagai output untuk mengirimkan sinyal ultrasonik, sedangkan pin Echo dikonfigurasi sebagai input untuk menerima pantulan sinyal tersebut.
- Load Cell dengan Modul HX711: Pin data dan clock dari modul HX711 dikonfigurasi sebagai input untuk membaca sinyal dari load cell.
- Servo Motor: Pin yang terhubung ke sinyal kontrol servo dikonfigurasi sebagai output untuk mengendalikan posisi servo.

Pengaturan ini dilakukan menggunakan fungsi pinMode(), seperti pinMode(triggerPin, OUTPUT); atau pinMode(echoPin, INPUT);.

### 2.8.3 Kalibrasi Sensor Load Cell

Load cell merupakan komponen penting dalam sistem CatPour untuk mengukur berat pakan yang tersedia. Namun, sensor ini memerlukan kalibrasi awal untuk memastikan akurasi pengukuran. Kalibrasi meliputi penyesuaian offset dan skala (scale factor) agar pembacaan berat sesuai dengan nilai sebenarnya. Proses kalibrasi ini biasanya dilakukan dalam fungsi setup() agar sistem siap melakukan pengukuran yang akurat sejak awal operasi.

### 2.8.4 Inisialisasi Perpustakaan (Library) Tambahan

Sistem CatPour mungkin menggunakan berbagai perpustakaan tambahan untuk mempermudah pengendalian komponen, seperti:

- Servo.h: Untuk mengendalikan servo motor dengan mudah.
- HX711.h: Untuk membaca data dari modul HX711 yang terhubung ke load cell.
- Ultrasonic.h: Untuk mempermudah pengoperasian sensor ultrasonik HC-SR04.

Inisialisasi perpustakaan ini dilakukan dalam fungsi setup() untuk memastikan bahwa semua fungsi dan metode yang diperlukan tersedia selama operasi sistem.

### 2.8.5 Penjadwalan Waktu dan Timer

Jika sistem CatPour dirancang untuk memberikan pakan pada waktu-waktu tertentu, maka penjadwalan waktu perlu diatur dalam fungsi setup(). Hal ini dapat melibatkan inisialisasi modul RTC (Real-Time Clock) seperti DS3231 untuk menjaga akurasi waktu, atau menggunakan fungsi millis() untuk penjadwalan berbasis waktu internal Arduino.

### 2.8.6 Inisialisasi Status Awal Sistem

Sebelum sistem mulai beroperasi, penting untuk menetapkan status awal dari berbagai variabel dan komponen. Misalnya, memastikan bahwa servo motor berada pada posisi tertutup, indikator LED dalam keadaan mati, dan variabel status sistem diatur ke mode siaga. Hal ini mencegah perilaku tak terduga saat sistem mulai berjalan.

### 2.8.7 Contoh Implementasi Fungsi setup()

Berikut adalah contoh implementasi fungsi setup() dalam sistem CatPour:

#include <Servo.h>

#include "HX711.h"

#include <Ultrasonic.h>

// Definisi pin

const int triggerPin = 9;

const int echoPin = 10;

const int servoPin = 6;

const int loadCellDoutPin = 3;

const int loadCellSckPin = 2;

// Inisialisasi objek

Servo pakanServo;

HX711 scale;

Ultrasonic ultrasonic(triggerPin, echoPin);

void setup() {

// Inisialisasi komunikasi serial

Serial.begin(9600);

// Konfigurasi pin

pinMode(triggerPin, OUTPUT);

pinMode(echoPin, INPUT);

pinMode(servoPin, OUTPUT);

// Inisialisasi servo

pakanServo.attach(servoPin);

pakanServo.write(0); // Posisi awal tertutup

// Inisialisasi load cell

scale.begin(loadCellDoutPin, loadCellSckPin);

scale.set_scale(); // Sesuaikan dengan nilai kalibrasi

scale.tare(); // Reset berat awal ke nol

// Inisialisasi sensor ultrasonik

// Tidak diperlukan konfigurasi tambahan jika menggunakan library Ultrasonic.h

// Inisialisasi status sistem

// Misalnya, mengatur variabel status ke mode siaga

}

Dengan struktur seperti di atas, fungsi setup() memastikan bahwa semua komponen sistem CatPour siap beroperasi dengan kondisi awal yang tepat, memungkinkan fungsi loop() untuk menjalankan logika utama otomatisasi dengan lancar.

### 2.8.8 Pentingnya Fungsi setup() dalam Sistem Otomatisasi

Fungsi setup() bukan hanya sekadar inisialisasi; ia merupakan fondasi dari keseluruhan sistem otomatisasi. Kesalahan atau kelalaian dalam konfigurasi awal dapat menyebabkan malfungsi, pembacaan sensor yang tidak akurat, atau bahkan kerusakan pada komponen. Oleh karena itu, perhatian khusus harus diberikan dalam merancang dan mengimplementasikan fungsi setup() untuk memastikan keandalan dan efisiensi sistem secara keseluruhan.

Dengan pemahaman mendalam tentang fungsi setup(), pengembang dapat merancang sistem otomatisasi seperti CatPour yang lebih stabil, responsif, dan andal dalam jangka panjang.

Loop Utama: Fungsi loop()

Setelah fungsi setup() selesai dieksekusi, program akan masuk ke fungsi loop(). Seperti namanya, blok kode ini akan berjalan secara terus-menerus dan berulang selama Arduino Nano mendapatkan daya. Ini adalah jantung operasional dari sistem CatPour, di mana semua logika utama otomatisasi reside. Di dalam loop(), mikrokontroler secara berkala melakukan pembacaan dari sensor, seperti membaca jarak dari HC-SR04 untuk mendeteksi mangkuk, dan membaca berat pakan dari load cell melalui HX711. Berdasarkan data sensor ini, program akan melakukan pengambilan keputusan yang cerdas. Misalnya, jika mangkuk terdeteksi dan waktu sesuai jadwal serta pakan di bawah ambang batas, maka program akan memicu pengaktifan servo motor untuk mengeluarkan pakan. Fungsi loop() juga bertanggung jawab untuk mempertahankan mode siaga ketika tidak ada kondisi yang memerlukan tindakan, menjamin efisiensi energi dan responsivitas sistem secara keseluruhan.

### 2.8 Loop Utama: Fungsi loop()

Setelah fungsi setup() selesai dieksekusi, program Arduino akan memasuki fungsi loop(). Fungsi ini merupakan inti dari sistem CatPour, karena di sinilah semua logika utama otomatisasi dijalankan secara berulang selama mikrokontroler mendapatkan daya. Fungsi loop() akan terus berulang, memungkinkan program untuk merespons perubahan kondisi secara real-time.

### 2.8.1 Struktur dan Peran Fungsi loop()

Fungsi loop() pada Arduino berfungsi sebagai pengganti fungsi main() dalam bahasa pemrograman C/C++. Setelah setup() selesai, loop() akan dieksekusi berulang kali, memungkinkan program untuk terus memantau dan merespons input dari sensor atau perubahan kondisi lainnya. (arduino.cc) (https://www.arduino.cc/en/Reference/Loop?utm_source=chatgpt.com)

Dalam konteks CatPour, fungsi loop() bertanggung jawab untuk:

1. Pembacaan Sensor: Secara berkala membaca data dari sensor ultrasonik HC-SR04 untuk mendeteksi keberadaan kucing dan dari sensor load cell melalui modul HX711 untuk mengukur berat pakan.
2. Pengambilan Keputusan: Berdasarkan data sensor, program menentukan apakah perlu mengaktifkan servo motor untuk mengeluarkan pakan, mempertimbangkan faktor seperti waktu, keberadaan kucing, dan berat pakan yang tersisa.
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

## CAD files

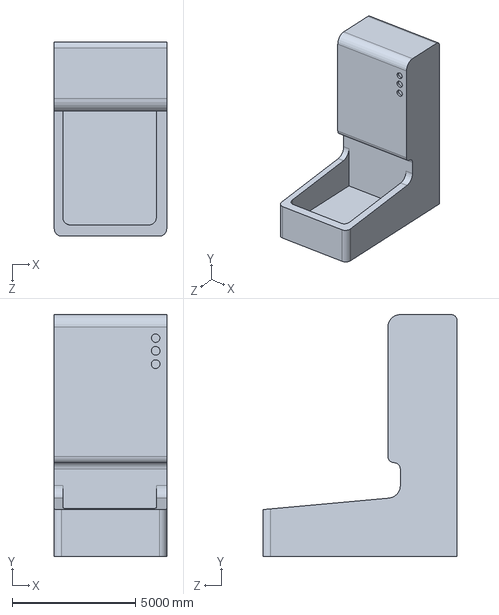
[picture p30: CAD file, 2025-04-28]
3D/Desain 3D sldwrk.SLDPRT
4572.0 x 9829.8 x 7899.4 mm

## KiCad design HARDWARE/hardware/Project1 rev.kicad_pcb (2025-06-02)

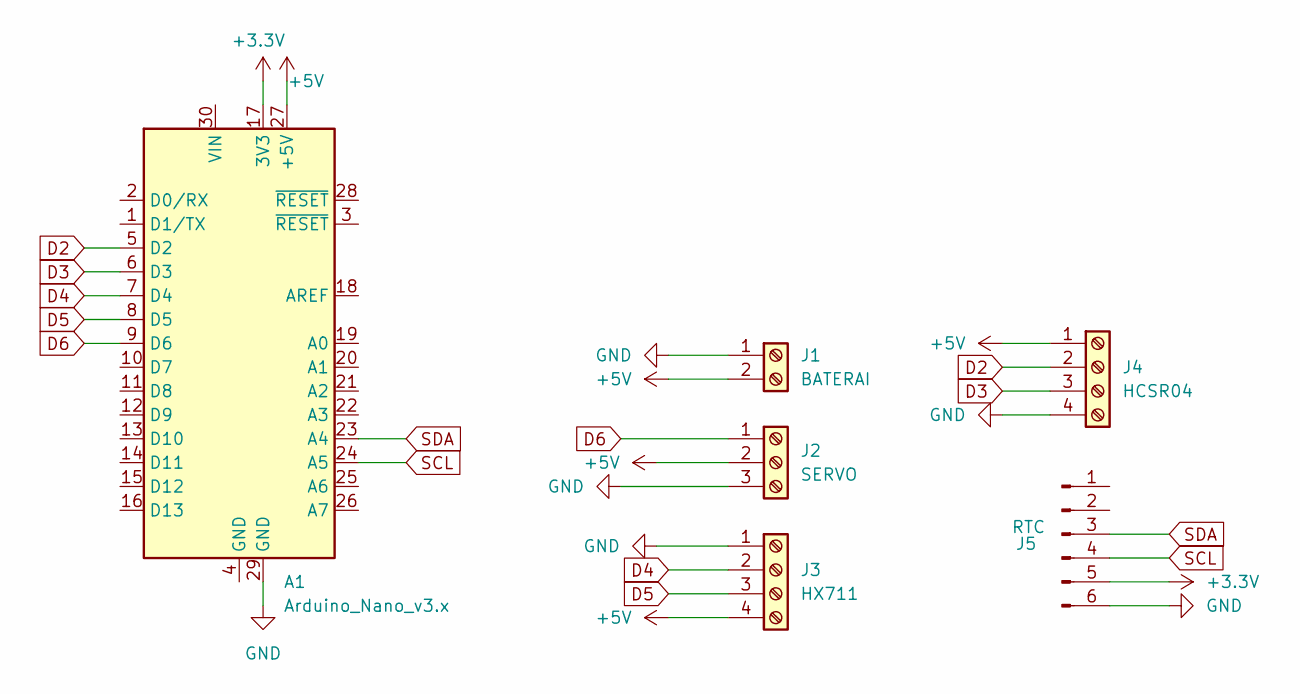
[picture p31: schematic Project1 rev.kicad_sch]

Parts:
A1: Arduino_Nano_v3.x; Arduino_Nano
J1: BATERAI; TerminalBlock_Phoenix_PT-1,5-2-5.0-H_1x02_P5.00mm_Horizontal
J2: SERVO; TerminalBlock_Phoenix_PT-1,5-3-5.0-H_1x03_P5.00mm_Horizontal
J3: HX711; TerminalBlock_Phoenix_PT-1,5-4-5.0-H_1x04_P5.00mm_Horizontal
J4: HCSR04; TerminalBlock_Phoenix_PT-1,5-4-5.0-H_1x04_P5.00mm_Horizontal
J5: RTC; PinSocket_1x06_P2.54mm_Vertical

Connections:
+3.3V: A1.17 (3V3), J5.5
+5V: A1.27 (+5V), J1.2, J2.2, J3.4, J4.1
D2: A1.5 (D2), J4.2
D3: A1.6 (D3), J4.3
D4: A1.7 (D4), J3.2
D5: A1.8 (D5), J3.3
D6: A1.9 (D6), J2.1
GND: A1.29 (GND), J1.1, J2.3, J3.1, J4.4, J5.6
SCL: A1.24 (A5), J5.4
SDA: A1.23 (A4), J5.3

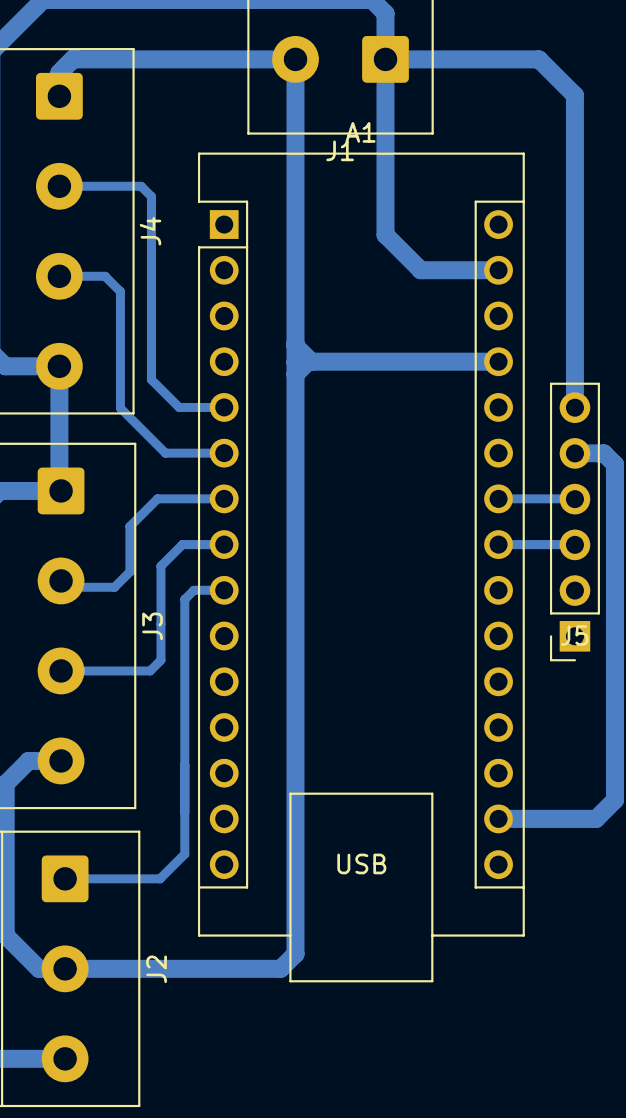
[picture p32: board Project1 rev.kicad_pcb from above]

Board: 2 copper layers, 6 parts (0 on the bottom side), 10 nets.

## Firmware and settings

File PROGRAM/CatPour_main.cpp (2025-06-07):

#define F_CPU 16000000UL
#include <avr/io.h>
#include <avr/interrupt.h>
#include <util/delay.h>
#include <string.h>
#include <stdio.h>
#include <stdlib.h>

// === Pin Definition ===
#define SERVO_PIN PB0
#define HX711_DT PD4
#define HX711_SCK PD5
#define TRIG_PIN PD2
#define ECHO_PIN PD3

// === Global Variable ===
volatile uint8_t feeding = 0;
volatile int currentAngle = 0;
char serialBuffer[32];
uint8_t serialIndex = 0;

// === Function Declarations ===
void USART_init();
void USART_send(char data);
void USART_print(const char* str);
void init_servo();
void set_servo_angle(uint8_t angle);
void hx711_init();
float hx711_read_grams();
float read_distance_cm();
void handle_command(const char* cmd);
void send_data();

// === USART Init ===
void USART_init() {
  UBRR0H = 0;
  UBRR0L = 103; // 9600 baud
  UCSR0B = (1 << RXEN0) | (1 << TXEN0);
  UCSR0C = (1 << UCSZ01) | (1 << UCSZ00);
}

void USART_send(char data) {
  while (!(UCSR0A & (1 << UDRE0)));
  UDR0 = data;
}

void USART_print(const char* str) {
  while (*str) USART_send(*str++);
}

// === Servo PWM via Timer1 ===
void init_servo() {
  DDRB |= (1 << SERVO_PIN);
  TCCR1A = (1 << COM1A1) | (1 << WGM11);
  TCCR1B = (1 << WGM13) | (1 << WGM12) | (1 << CS11); // prescaler 8
  ICR1 = 40000; // 20ms period
  OCR1A = 1000; // default 0 deg
}

void set_servo_angle(uint8_t angle) {
  uint16_t pulse = 1000 + ((uint32_t)angle * 1000) / 180; // 1000-2000us
  OCR1A = pulse;
  currentAngle = angle;
}

// === HX711 Reading ===
void hx711_init() {
  DDRD &= ~(1 << HX711_DT); // input
  DDRD |= (1 << HX711_SCK); // output
  PORTD &= ~(1 << HX711_SCK);
}

long hx711_read_raw() {
  while (!(PIND & (1 << HX711_DT))); // tunggu data ready
  long value = 0;
  for (uint8_t i = 0; i < 24; i++) {
    PORTD |= (1 << HX711_SCK);
    _delay_us(1);
    value = (value << 1) | ((PIND & (1 << HX711_DT)) ? 1 : 0);
    PORTD &= ~(1 << HX711_SCK);
    _delay_us(1);
  }

  // 25th pulse untuk gain 128
  PORTD |= (1 << HX711_SCK);
  _delay_us(1);
  PORTD &= ~(1 << HX711_SCK);
  _delay_us(1);

  if (value & 0x800000) value |= 0xFF000000; // tanda negatif
  return value;
}

float hx711_read_grams() {
  long raw = hx711_read_raw();
  float calibrated = (raw - 8300000) / 984.0; // kalibrasi manual
  return calibrated;
}

// === Ultrasonik ===
float read_distance_cm() {
  // TRIG: Output, ECHO: Input
  DDRD |= (1 << TRIG_PIN);
  DDRD &= ~(1 << ECHO_PIN);
  PORTD &= ~(1 << TRIG_PIN);
  _delay_us(2);
  PORTD |= (1 << TRIG_PIN);
  _delay_us(10);
  PORTD &= ~(1 << TRIG_PIN);

  // Wait for echo high
  uint32_t timeout = 30000;
  while (!(PIND & (1 << ECHO_PIN)) && timeout--) _delay_us(1);

  uint32_t count = 0;
  while ((PIND & (1 << ECHO_PIN)) && count < 30000) {
    _delay_us(1);
    count++;
  }

  float distance = (count * 0.0343) / 2;
  return distance;
}

// === Perintah Serial ===
void handle_command(const char* cmd) {
  if (strcmp(cmd, "beri") == 0) {
    set_servo_angle(180);
    feeding = 1;
    USART_print("Memberi makan...\r\n");
  } else {
    USART_print("Perintah tidak dikenal.\r\n");
  }
}

// === Kirim Data ===
void send_data() {
  float jarak = read_distance_cm();
  float berat = hx711_read_grams();
  float kapasitas = (14.0 - jarak) / 12.0 * 100.0;
  if (kapasitas < 0) kapasitas = 0;
  if (kapasitas > 100) kapasitas = 100;

  if (feeding && berat >= 200.0) {
    set_servo_angle(0);
    feeding = 0;
    USART_print("Berat 200g tercapai. Servo ditutup.\r\n");
  }

  char buffer[64];
  USART_print("======================================\r\n");
  sprintf(buffer, "Servo           : %s (%d derajat)\r\n", currentAngle == 0 ? "TUTUP" : "BUKA", currentAngle);
  USART_print(buffer);
  sprintf(buffer, "Kapasitas       : %.1f %%\r\n", kapasitas);
  USART_print(buffer);
  sprintf(buffer, "Berat Timbangan : %.2f gram\r\n", berat);
  USART_print(buffer);
  sprintf(buffer, "Jarak Sensor    : %.2f cm\r\n", jarak);
  USART_print(buffer);
  USART_print("======================================\r\n\r\n");
}

int main(void) {
  USART_init();
  init_servo();
  set_servo_angle(0);
  hx711_init();
  _delay_ms(100);

  USART_print("Sistem siap. Ketik 'beri' untuk memberi makan.\r\n");

  while (1) {
    // Serial input
    if (UCSR0A & (1 << RXC0)) {
      char c = UDR0;
      if (c == '\n' || c == '\r') {
        if (serialIndex > 0) {
          serialBuffer[serialIndex] = '\0';
          handle_command(serialBuffer);
          serialIndex = 0;
        }
      } else if (serialIndex < sizeof(serialBuffer) - 1) {
        serialBuffer[serialIndex++] = c;
      }
    }

    send_data();
    _delay_ms(1000);
  }
}

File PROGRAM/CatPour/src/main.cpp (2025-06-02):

#include <Servo.h>
#include "HX711.h"

// === Pin Definition ===
#define DT 4
#define SCK 5
#define SERVO_PIN 6
#define TRIG_PIN 2
#define ECHO_PIN 3

// === Global ===
Servo myServo;
HX711 scale;

String serialInput = "";
bool feeding = false;
int currentAngle = 0;

// === Fungsi ===
void handleCommand(String cmd);
float readDistanceCM();

void setup() {
  Serial.begin(9600);

  // Servo setup
  myServo.attach(SERVO_PIN);
  myServo.write(0); // Posisi awal
  currentAngle = 0;

  // HX711 setup
  scale.begin(DT, SCK);
  scale.set_scale(984.0);  // kalibrasi sesuai sensor
  delay(2000);
  scale.tare();

  // Ultrasonik setup
  pinMode(TRIG_PIN, OUTPUT);
  pinMode(ECHO_PIN, INPUT);

  Serial.println("Sistem siap. Ketik 'beri' untuk memberi makan.");
}

void loop() {
  // === Serial input ===
  if (Serial.available()) {
    char c = Serial.read();
    if (c == '\n' || c == '\r') {
      if (serialInput.length() > 0) {
        handleCommand(serialInput);
        serialInput = "";
      }
    } else {
      serialInput += c;
    }
  }

  // === Baca sensor ===
  float jarak = readDistanceCM();
  float berat = scale.get_units();

  // Hitung kapasitas
  float kapasitas = (14.0 - jarak) / 12.0 * 100.0;
  if (kapasitas < 0) kapasitas = 0;
  if (kapasitas > 100) kapasitas = 100;

  // Jika sedang feeding dan berat cukup
  if (feeding && berat >= 200.0) {
    myServo.write(0);
    currentAngle = 0;
    feeding = false;
    Serial.println("Berat 200g tercapai. Servo ditutup.");
  }

  // === Tampilkan data ke Serial Monitor ===
  Serial.println("======================================");
  Serial.print("Servo           : ");
  Serial.print(currentAngle == 0 ? "TUTUP" : "BUKA");
  Serial.print(" (");
  Serial.print(currentAngle);
  Serial.println(" derajat)");

  Serial.print("Kapasitas       : ");
  Serial.print(kapasitas, 1);
  Serial.println(" %");

  Serial.print("Berat Timbangan : ");
  Serial.print(berat, 2);
  Serial.println(" gram");

  Serial.print("Jarak Sensor    : ");
  Serial.print(jarak, 2);
  Serial.println(" cm");
  Serial.println("======================================\n");

  delay(1000);
}

void handleCommand(String cmd) {
  cmd.trim();
  cmd.toLowerCase();
  if (cmd == "beri") {
    myServo.write(180);
    currentAngle = 180;
    feeding = true;
    Serial.println("Memberi makan...");
  } else {
    Serial.println("Perintah tidak dikenal.");
  }
}

// Fungsi jarak ultrasonik
float readDistanceCM() {
  digitalWrite(TRIG_PIN, LOW);
  delayMicroseconds(2);
  digitalWrite(TRIG_PIN, HIGH);
  delayMicroseconds(10);
  digitalWrite(TRIG_PIN, LOW);

  long duration = pulseIn(ECHO_PIN, HIGH, 30000); // timeout 30ms
  float distance = duration * 0.0343 / 2;

  return distance;
}

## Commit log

2025-04-26 Menambahkan .gitkeep di semua folder kosong
2025-05-04 Pesan commit kamu di sini
    [Project1 rev.kicad_pcb, Project1 rev.kicad_sch]
